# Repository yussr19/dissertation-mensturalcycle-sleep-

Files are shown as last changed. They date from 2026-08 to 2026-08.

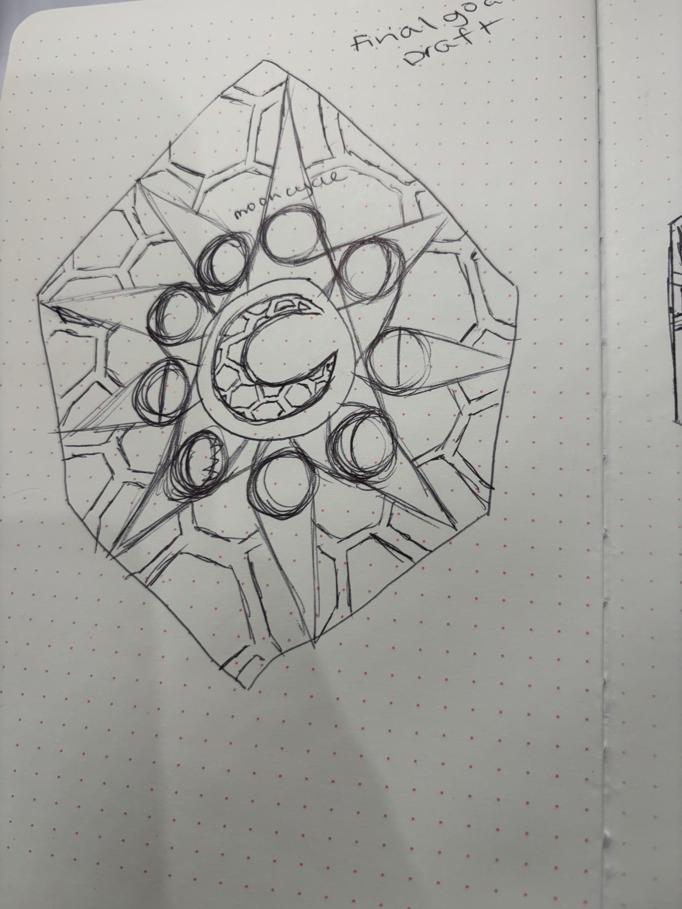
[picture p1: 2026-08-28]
sketches/IMG_7631 (2).jpeg

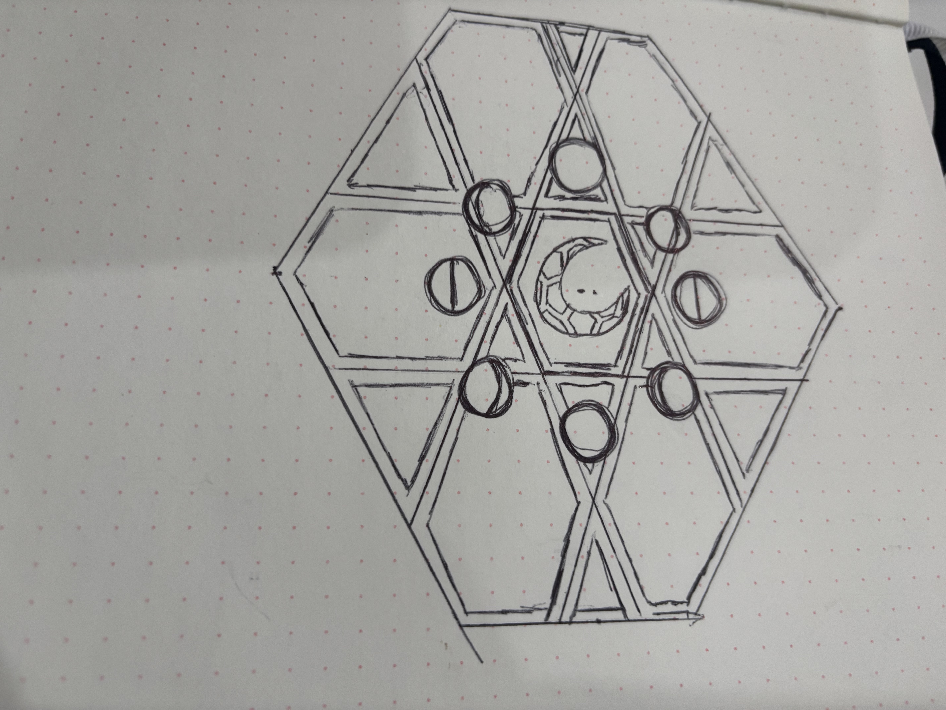
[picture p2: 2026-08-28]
sketches/IMG_7632 (1).jpeg

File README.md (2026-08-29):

# Luna — menstrual cycle and sleep sensing

A bedside sensing system that records sleep across a menstrual cycle and
renders the result as a physical drawing.

An LDC2410C mmWave radar and a Bangle.js 2 smartwatch log sleep to a
Raspberry Pi beside the bed. Nightly aggregation produces a sleep quality
score from 1 to 10, which is published over MQTT. An Arduino Nano 33 IoT
subscribes to that topic and drives a pen arm and a rotating disc, tracing
28 days of sleep as a spiral.

The recorder borrows its pen from a barograph — an instrument that has
drawn atmospheric pressure onto rotating paper since the nineteenth
century. Luna applies the same mechanism to a different cycle.

---

## Contents

- [How it works](#how-it-works)
- [Bill of materials](#bill-of-materials)
- [Repository layout](#repository-layout)
- [Part 1 — Bedside device](#part-1--bedside-device)
- [Part 2 — Luna recorder](#part-2--luna-recorder)
- [Part 3 — Exhibition mode](#part-3--exhibition-mode)
- [Enclosures](#enclosures)
- [Datasets](#datasets)
- [Analysis](#analysis)
- [Troubleshooting](#troubleshooting)
- [Known limitations](#known-limitations)

---

## How it works

```
Bangle.js 2                      LDC2410C radar
HR, IBI, survey                  presence, movement
     |                                 |
     | BLE                             | UART
     v                                 v
        Bedside Pi  —  sleeppi
        finalsleep.db · log_sleep.py · log_radar.py
        compute_sleep_metrics.py · compute_composite.py
        publish_sleep.py
                      |
                      | publish
                      v
        MQTT broker — mqtt.cetools.org:1884
        student/CASA0022/yussr/sleepquality
                      |
                      | subscribe
                      v
        Luna recorder — Arduino Nano 33 IoT
                   |            |
            SG90 pen arm    28BYJ-48 disc
          traces quality    1 turn / 28 days
```

The radar gives binary presence and movement. The Bangle gives heart rate
and inter-beat intervals. Together these produce sleep duration, efficiency,
wake after sleep onset (WASO) and movement percentage, which are combined
into a single 1–10 composite score per night.

---

## Bill of materials

### Bedside device

| Item | Qty | Notes | Approx. cost |
|---|-----|---|---|
| Raspberry Pi 3 Model A+ | 1 | Runs logging and nightly aggregation | £23 |
| microSD card, 32GB+ | 1 | Raspberry Pi OS | £8 |
| Official Pi power supply | 1 | Underpowered supplies cause boot failures | £10 |
| LDC2410C mmWave radar | 1 | UART presence/movement sensor | £6–10 |
| Bangle.js 2 smartwatch | 1 | Heart rate, IBI, morning survey | £99.60 |
| Jumper wires, female-female | 4 | Radar to Pi GPIO | £6 per pack |
| 3D printed sleep enclosure | 1 | `fusion/sleep enclousre final.stl` | filament only |

Subtotal: roughly **£153–157**, dominated by the smartwatch.

The Pi 3 Model A+ has 512MB of RAM and no Ethernet port. It is adequate for
logging and nightly aggregation, but it will not comfortably run a desktop
environment or a remote code editor alongside the sensing scripts. Work on
it over plain SSH rather than VS Code Remote, and keep anything non-essential
off it while it is recording.

### Luna recorder

| Item | Qty | Notes | Approx. cost |
|---|-----|---|---|
| Arduino Nano 33 IoT | 1 | WiFi + MQTT subscriber | £20–25 |
| SG90 micro servo | 1 | Pen arm, radial position | £3 |
| 28BYJ-48 stepper + ULN2003 driver | 1 | Usually sold as a pair | £5 |
| WS2812B LED strip, 28 LEDs | 1 | Exhibition lighting | £10 |
| Metcheck black fibre tip recording pen | 1 | Barograph nib, SKU MET-FIBRENIB | £16.50 |
| Paper discs | — | Cut to fit the turntable | £3 |
| 5V 2A power supply | 1 | Servo and stepper draw more than USB supplies | £10 |
| 3D printed recorder body | 1 | `fusion/luna recorder final.stl` | filament only |
| 3D printed pen dial and holder | 1 | `fusion/pen dial and holder.stl` | filament only |

Subtotal: roughly **£68–73**, excluding filament.

### Total

**Roughly £221–230** for the complete system.

Prices are UK retail including VAT, correct as of August 2026. The Bangle.js
2 figure comes from Espruino's shop and The Pi Hut; the recording pen from
Metcheck. 

### The pen

The pen is a barograph nib rather than an ordinary fineliner. It is 20.3mm
long and 4mm wide, with two dovetail grooves on the back that slot onto a
recording arm, and the nib lasts around twelve months of continuous use.
The pen holder in `fusion/pen dial and holder.stl` is dimensioned for these
grooves — an ordinary pen will not seat correctly without modifying the
model.

### Wiring — Luna recorder

| Component | Pin |
|---|-----|
| SG90 servo signal | D6 |
| 28BYJ-48 via ULN2003 IN1 | D8 |
| 28BYJ-48 via ULN2003 IN2 | D10 |
| 28BYJ-48 via ULN2003 IN3 | D9 |
| 28BYJ-48 via ULN2003 IN4 | D11 |

Note the IN2/IN3 ordering — it is not sequential. This matches the
`Stepper disc(STEPS_PER_REV, 8, 10, 9, 11)` declaration in the sketch.

### Wiring — LDC2410C to Raspberry Pi

| LDC2410C | Pi header pin |
|---|---|
| VCC | 2 or 4 (5V) |
| GND | 6 |
| TX | 10 (GPIO15, Pi RX) |
| RX | 8 (GPIO14, Pi TX) |

Diagrams and placement notes are in `sketches/`.

---

## Repository layout

| Path | Contents |
|---|---|
| `final_code/bedside_device/` | Logging, metrics and publishing on the bedside Pi |
| `final_code/exhibition/` | Exhibition publisher and the Arduino sketch |
| `test_code/` | Hardware sanity-check scripts |
| `analysis/` | Statistics and figure generation |
| `datasets/` | Exported sleep, radar and survey data |
| `fusion/` | Fusion 360 sources and STL exports |
| `sketches/` | Diagrams and design notes |

---

## Part 1 — Bedside device

### Prepare the Pi

Flash Raspberry Pi OS, then free the serial port for the radar:

```bash
sudo raspi-config
# Interface Options -> Serial Port
#   login shell over serial?      -> No
#   serial port hardware enabled? -> Yes
sudo reboot
```

### Install dependencies

```bash
sudo apt update
sudo apt install -y python3-pip sqlite3
pip3 install pyserial paho-mqtt bleak
```

### Clone and test

```bash
git clone https://github.com/yussr19/dissertation-mensturalcycle-sleep-.git
cd dissertation-mensturalcycle-sleep-
python3 test_code/test_radar.py
```

Walk in front of the sensor. You should see `presence=True movement=True`,
then `movement=False` when you sit still. If nothing prints, see
[Troubleshooting](#troubleshooting).

### The pipeline

| Script | Purpose |
|---|---|
| `log_radar.py` | Logs presence and movement to `finalsleep.db` |
| `log_sleep.py` | Logs Bangle.js data to `finalsleep.db` |
| `sync_bangle.py` | Pulls JSON off the watch over BLE into SQLite |
| `compute_sleep_metrics.py` | Duration, efficiency, WASO, movement % |
| `compute_composite.py` | Combines metrics into a 1–10 score |
| `publish_sleep.py` | Publishes the score to MQTT |

`log_radar.py` runs continuously overnight. The compute and publish steps
run once per day after waking.

To schedule them, add entries to the Pi's crontab with `crontab -e`. For
example, to run the daily chain at 10am:

```
0 10 * * * cd /home/USER/dissertation-mensturalcycle-sleep-/final_code/bedside_device && /usr/bin/python3 compute_sleep_metrics.py
5 10 * * * cd /home/USER/dissertation-mensturalcycle-sleep-/final_code/bedside_device && /usr/bin/python3 compute_composite.py
10 10 * * * cd /home/USER/dissertation-mensturalcycle-sleep-/final_code/bedside_device && /usr/bin/python3 publish_sleep.py
```

Use absolute paths — cron does not inherit your shell environment, and
relative paths are the most common reason a scheduled script works by hand
but silently fails overnight.

---

## Part 2 — Luna recorder

### Arduino setup

Install the Arduino IDE, add the **Arduino SAMD Boards** package, select
**Arduino Nano 33 IoT**, and install these libraries via Library Manager:

- WiFiNINA
- PubSubClient
- Servo
- Stepper
- ArduinoJson

### Credentials

The sketch reads credentials from `config.h`, which is not in this
repository. Create it from the template:

```bash
cd final_code/exhibition/final_exhib
cp config.example.h config.h
```

Fill in your MQTT username and password and up to two WiFi networks. The
sketch tries them in order, which is useful when moving between a home
network and a venue.

### Calibration

Two constants in the sketch set where the pen sits:

```cpp
const int ANGLE_Q1  = 20;   // sleep quality 1  — inner ring
const int ANGLE_Q10 = 160;  // sleep quality 10 — outer ring
```

Adjust these after assembly so the pen reaches the inner and outer edges of
the paper without binding.

### Flash and check

Upload the sketch, open Serial Monitor at 9600 baud. You should see the WiFi
and MQTT connections succeed, then `Waiting for sleep-quality data...`.

---

## Part 3 — Exhibition mode

For an exhibition the bedside Pi is not present, so a second Pi replays a
recorded 28-day cycle from the database.

```bash
export MQTT_USER="your_username"
export MQTT_PASS="your_password"

cd final_code/exhibition
python3 publish_exhibition.py --inspect        # check the data first
python3 publish_exhibition.py --seed           # fill the recorder history
python3 publish_exhibition.py --interval 10    # fast test
python3 publish_exhibition.py                  # live: one day per 10 min
```

The publisher sends one small JSON message per day:

```json
{"quality": 7, "cycle_day": 12}
```

Messages are retained, so a recorder that is power-cycled mid-exhibition
picks up the current value immediately rather than standing still.

Put the credentials in `~/.bashrc` so they survive reboots:

```bash
echo 'export MQTT_USER="your_username"' >> ~/.bashrc
echo 'export MQTT_PASS="your_password"' >> ~/.bashrc
source ~/.bashrc
```

---

## Enclosures

`fusion/` holds both Fusion 360 sources and STL exports.

| File | Part |
|---|---|
| `luna recorder final.stl` | Recorder body |
| `pen dial and holder.stl` | Pen arm and dial |
| `sleep enclousre final.stl` | Bedside sensor housing |

The `.f3d` and `.f3z` files are the editable Fusion 360 sources. The STLs
are ready to slice.

---

## Datasets

| File | Contents |
|---|---|
| `datasets/sleep_log.csv` | Nightly sleep records and composite scores |
| `datasets/radar_sample.csv` | Radar output samples |
| `datasets/survey_responses.csv` | 17 exhibition visitor responses |

Survey responses record date, gender, age band and one comprehension
question. They carry no names, emails or precise timestamps.

---

## Analysis

```bash
cd analysis
python3 results_statistics.py
python3 make_figure_5_1.py
```

`make_figure_5_1.py` produces the 28-day circular visualisation.

Both scripts read from the sleep database. If you are reproducing this
without the original database, point them at `datasets/sleep_log.csv`
instead by editing the path at the top of each script.

---

## Troubleshooting

**Radar prints nothing.** Almost always baud rate or the serial console.
The LDC2410C defaults to 256000, though some boards ship at 115200. Confirm
the serial console is disabled in `raspi-config`.

**Presence flickers.** A single frame reading "no target" mid-sleep is
normal. Aggregation applies a hold timer so a brief dropout is not read as
someone leaving the bed.

**Sitting still reads as absent.** Stationary detection depends on the
per-gate sensitivity thresholds and on what is behind the person. This is
tuning, not a fault.

**Recorder connects but never moves.** Check the payload keys are exactly
`quality` and `cycle_day`. The sketch uses `StaticJsonDocument<128>`, so an
oversized message fails to deserialize and is silently ignored.

**Recorder drops off MQTT during replay.** `replayHistory()` blocks while
it sweeps, during which `mqtt.loop()` does not run. Long sweeps can exceed
the keepalive. It reconnects, but messages arriving mid-sweep are lost.

**Scheduled scripts work by hand but not overnight.** Cron runs with a
minimal environment. Use absolute paths and check `/var/log/syslog`.

---

## Known limitations

- The LDC2410C reports presence along a single beam. It does not count people
  or track position, so the system assumes one occupant.
- Sleep staging is inferred from movement and heart rate, not EEG. Values are
  relative indicators rather than clinical measurements.
- The disc advances during replay as well as on its own schedule; over a long
  exhibition these two can drift out of step.
- MQTT credentials are transmitted without TLS on port 1884.
- The recorder holds 28 days in memory with no persistence. A power cycle
  loses the history until the publisher re-seeds it.

---

## License

MIT.

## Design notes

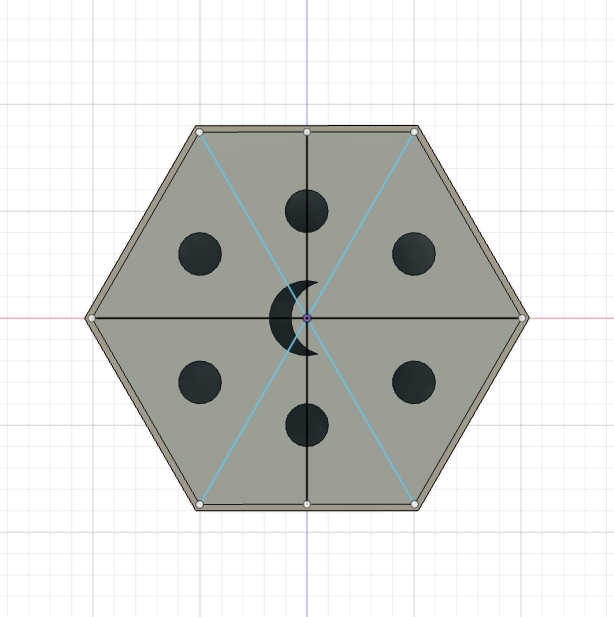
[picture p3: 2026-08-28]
sketches/Screenshot%202026-06-07%20at%2019.21.58.png

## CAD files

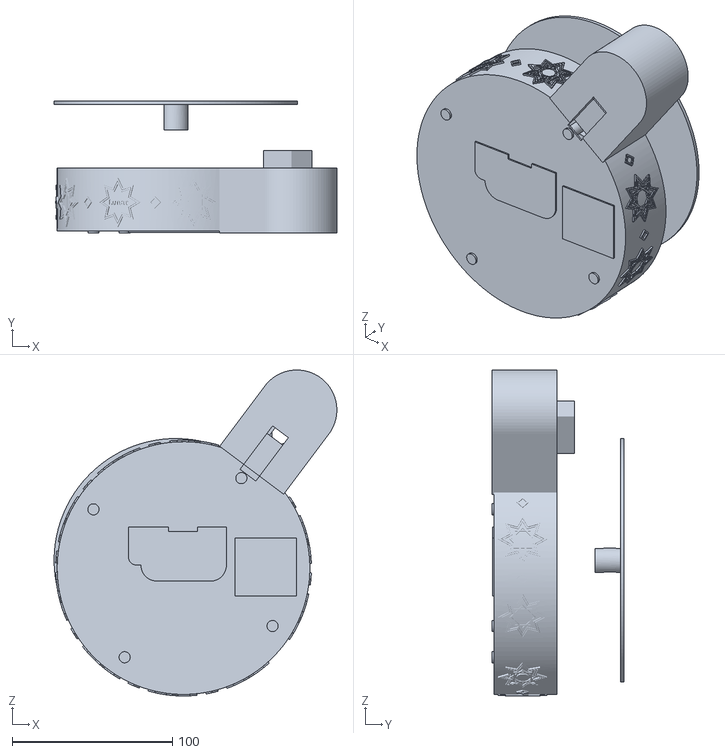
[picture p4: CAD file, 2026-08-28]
fusion/luna recorder final.stl
176.5 x 82.3 x 203.5

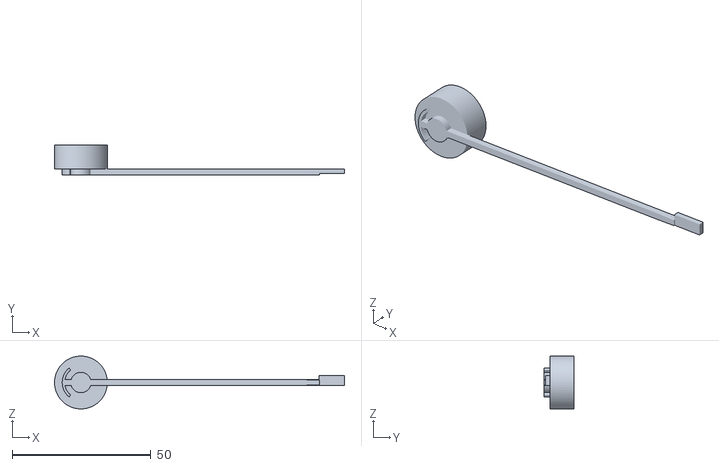
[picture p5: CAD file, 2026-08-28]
fusion/pen dial and holder.stl
104.5 x 10.7 x 19.0

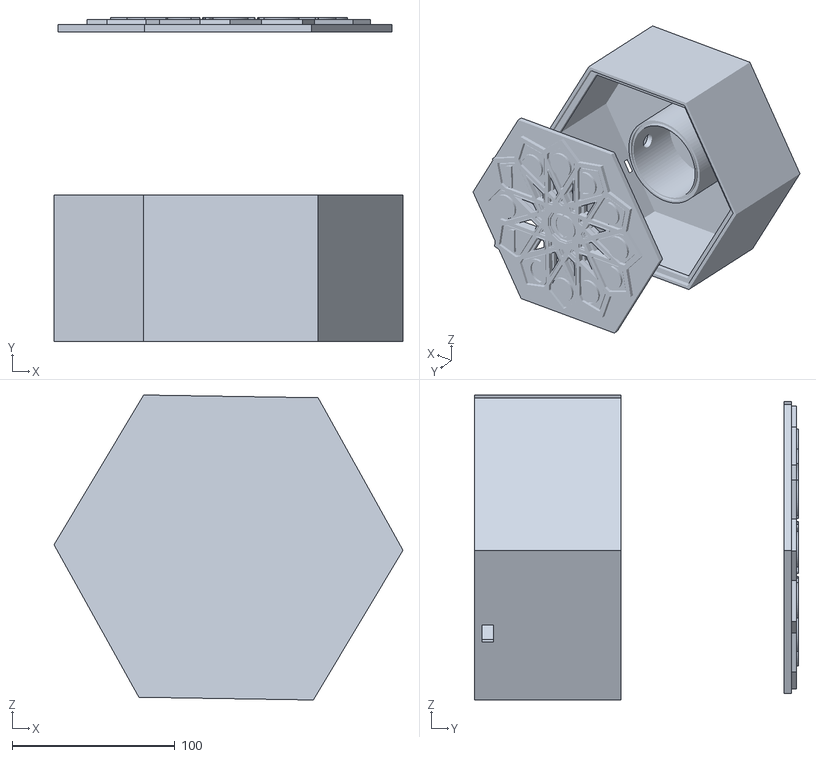
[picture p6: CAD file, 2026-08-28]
fusion/sleep enclousre final.stl
214.7 x 199.4 x 187.7

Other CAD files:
fusion/fusion/luna recorder final.f3z
fusion/pen dial and holder final.f3d
fusion/sleep enclousre final.f3d

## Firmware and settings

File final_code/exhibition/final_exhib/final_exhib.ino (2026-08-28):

#include "config.h"

#include <WiFiNINA.h>
#include <PubSubClient.h>
#include <Servo.h>
#include <Stepper.h>
#include <ArduinoJson.h>

// ============================================================
// WIFI / MQTT
// ============================================================
// Credentials live in config.h, which is gitignored.
// Copy config.example.h to config.h and fill in your values.

const char* MQTT_BROKER = "mqtt.cetools.org";
const int   MQTT_PORT = 1884;

const char* TOPIC = "student/CASA0022/yussr/sleepquality";


// ============================================================
// HARDWARE
// ============================================================

const int SERVO_PIN = 6;
const int STEPS_PER_REV = 2048;

Stepper disc(STEPS_PER_REV, 8, 10, 9, 11);
Servo penArm;


// ============================================================
// SERVO CALIBRATION
// ============================================================

const int ANGLE_Q1  = 20;   // sleep quality 1  = inner ring
const int ANGLE_Q10 = 160;  // sleep quality 10 = outer ring


// ============================================================
// TIMING
// ============================================================

const unsigned long REPLAY_INTERVAL_MS = 600000UL;  // 10 minutes
unsigned long lastReplay = 0;


// ============================================================
// DATA
// ============================================================
// No synthetic data. These values are filled from MQTT.

int  history[28] = {0};
bool receivedDay[28] = {false};
int  receivedCount = 0;
int  latestQuality = 0;
int  latestCycleDay = 0;


// ============================================================
// NETWORK OBJECTS
// ============================================================

WiFiClient wifi;
PubSubClient mqtt(wifi);


// ============================================================
// SERVO
// ============================================================

int currentAngle = -1;

int qualityToAngle(int q) {
  q = constrain(q, 1, 10);
  return map(q, 1, 10, ANGLE_Q1, ANGLE_Q10);
}

void moveServoSlowly(int targetAngle, int stepDelayMs) {

  if (currentAngle == -1) {
    penArm.write(targetAngle);
    currentAngle = targetAngle;
    return;
  }

  int step = (targetAngle > currentAngle) ? 1 : -1;

  while (currentAngle != targetAngle) {
    currentAngle += step;
    penArm.write(currentAngle);
    delay(stepDelayMs);
  }
}


// ============================================================
// PRINT CURRENT HISTORY
// ============================================================

void printHistory() {

  Serial.println();
  Serial.println("Current 28-day history:");

  for (int i = 0; i < 28; i++) {
    Serial.print("Day ");
    Serial.print(i + 1);
    Serial.print(": ");
    if (receivedDay[i]) {
      Serial.println(history[i]);
    } else {
      Serial.println("-");
    }
  }

  Serial.print("Days received: ");
  Serial.print(receivedCount);
  Serial.println("/28");
  Serial.println();
}


// ============================================================
// MQTT CALLBACK
// ============================================================

void mqttCallback(char* topic, byte* payload, unsigned int len) {

  StaticJsonDocument<128> doc;

  DeserializationError error = deserializeJson(doc, payload, len);

  if (error) {
    Serial.print("JSON error: ");
    Serial.println(error.c_str());
    return;
  }

  if (!doc.containsKey("quality") || !doc.containsKey("cycle_day")) {
    Serial.println("MQTT message missing quality or cycle_day");
    return;
  }

  int q   = doc["quality"];
  int day = doc["cycle_day"];

  if (q < 1 || q > 10) {
    Serial.print("Invalid quality: ");
    Serial.println(q);
    return;
  }

  if (day < 1 || day > 28) {
    Serial.print("Invalid cycle day: ");
    Serial.println(day);
    return;
  }

  int index = day - 1;
  history[index] = q;

  if (!receivedDay[index]) {
    receivedDay[index] = true;
    receivedCount++;
  }

  latestQuality  = q;
  latestCycleDay = day;

  Serial.print("Received cycle day ");
  Serial.print(day);
  Serial.print(" | sleep quality ");
  Serial.println(q);

  moveServoSlowly(qualityToAngle(q), 20);

  if (receivedCount == 28) {
    Serial.println();
    Serial.println("FULL 28-DAY DATASET RECEIVED");
    printHistory();
  }
}


// ============================================================
// WIFI CONNECTION
// ============================================================

void connectWiFi() {

  const char* ssids[]  = { WIFI_SSID_1, WIFI_SSID_2 };
  const char* passes[] = { WIFI_PASS_1, WIFI_PASS_2 };

  for (int i = 0; i < 2 && WiFi.status() != WL_CONNECTED; i++) {

    Serial.print("WiFi try: ");
    Serial.println(ssids[i]);

    WiFi.begin(ssids[i], passes[i]);

    unsigned long start = millis();

    while (WiFi.status() != WL_CONNECTED && millis() - start < 15000) {
      delay(500);
    }
  }

  if (WiFi.status() == WL_CONNECTED) {
    Serial.println("WiFi connected");
    Serial.print("IP: ");
    Serial.println(WiFi.localIP());
  } else {
    Serial.println("WiFi connection failed");
  }
}


// ============================================================
// MQTT CONNECTION
// ============================================================

void connectMQTT() {

  if (WiFi.status() != WL_CONNECTED) return;

  while (!mqtt.connected()) {

    Serial.println("Connecting to MQTT...");

    if (mqtt.connect("luna-recorder", MQTT_USER, MQTT_PASSWD)) {

      Serial.println("MQTT connected");
      mqtt.subscribe(TOPIC);
      Serial.print("Subscribed to: ");
      Serial.println(TOPIC);

    } else {

      Serial.print("MQTT failed, state=");
      Serial.println(mqtt.state());
      delay(3000);
    }
  }
}


// ============================================================
// REPLAY THE RECEIVED 28-DAY DATA
// ============================================================

void replayHistory() {

  if (receivedCount == 0) {
    Serial.println("No data received yet.");
    return;
  }

  Serial.println();
  Serial.println("Starting received-data replay...");

  for (int day = 0; day < 28; day++) {

    if (!receivedDay[day]) continue;

    int q = history[day];

    Serial.print("Replay day ");
    Serial.print(day + 1);
    Serial.print(" quality ");
    Serial.println(q);

    // Move pen radially
    moveServoSlowly(qualityToAngle(q), 15);

    // Advance disc one cycle day: 2048 / 28 = ~73 steps
    int stepsPerDay = STEPS_PER_REV / 28;
    disc.step(stepsPerDay);

    delay(400);
  }

  Serial.println("Replay complete.");

  if (latestQuality >= 1) {
    moveServoSlowly(qualityToAngle(latestQuality), 15);
  }
}


// ============================================================
// SETUP
// ============================================================

void setup() {

  Serial.begin(9600);
  delay(1500);

  Serial.println();
  Serial.println("Luna recorder starting");

  penArm.attach(SERVO_PIN);
  disc.setSpeed(5);

  mqtt.setServer(MQTT_BROKER, MQTT_PORT);
  mqtt.setCallback(mqttCallback);

  connectWiFi();
  connectMQTT();

  lastReplay = millis();

  Serial.println("Waiting for sleep-quality data...");
}


// ============================================================
// LOOP
// ============================================================

void loop() {

  if (WiFi.status() != WL_CONNECTED) {
    connectWiFi();
  }

  if (WiFi.status() == WL_CONNECTED && !mqtt.connected()) {
    connectMQTT();
  }

  mqtt.loop();

  unsigned long now = millis();

  if (now - lastReplay >= REPLAY_INTERVAL_MS) {
    replayHistory();
    // replayHistory() blocks, so reset the timer after it returns
    lastReplay = millis();
  }
}

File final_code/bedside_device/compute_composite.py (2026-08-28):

#!/usr/bin/env python3

"""
compute_composite.py

Derives an equal-weight DEVICE-ONLY composite sleep index from
nightly measures stored in sleep_log.

The composite uses:
    - heart_rate
    - hrv
    - movement_pct
    - sleep_duration_min
    - sleep_efficiency

Subjective measures are deliberately excluded:
    - sleep_quality
    - energy

Each contributing measure is:
  1. z-scored across the full record
  2. reversed if high values mean worse sleep
  3. equally averaged
  4. rescaled to 1-10

This keeps the composite independent from the subjective app
and diary data so that device-derived and subjective measures
can be compared in the Results.

Usage:
    python3 compute_composite.py --dry-run
    python3 compute_composite.py
"""

import sqlite3
import sys
import statistics


DB_PATH = "/home/yussr19/analysis/finalsleep_.db"


# --------------------------------------------------
# DEVICE-ONLY CONTRIBUTORS
# --------------------------------------------------

CONTRIBUTORS = [

    (
        "heart_rate",
        False
    ),

    (
        "hrv",
        True
    ),

    (
        "movement_pct",
        False
    ),

    (
        "sleep_duration_min",
        True
    ),

    (
        "sleep_efficiency",
        True
    ),

]


# Subjective sleep quality is NOT included.
INCLUDE_SELF_REPORT = False

# A night may be missing at most one usable
# contributor before being excluded.
MAX_MISSING = 1


def existing_columns(conn):
    """Return sleep_log column names."""

    return {
        r[1]
        for r in conn.execute(
            "PRAGMA table_info(sleep_log)"
        ).fetchall()
    }


def fetch_rows(conn, contributors):
    """Load nightly rows."""

    cols = [
        "id",
        "date",
        "cycle_day",
        "sleep_quality",
        "energy",
    ] + [
        c
        for c, _
        in contributors
    ]

    # Remove duplicates while preserving order.
    cols = list(
        dict.fromkeys(cols)
    )

    q = (
        f"SELECT "
        f"{', '.join(cols)} "
        f"FROM sleep_log "
        f"ORDER BY id ASC"
    )

    return [
        dict(
            zip(cols, r)
        )
        for r
        in conn.execute(q).fetchall()
    ]


def zscores(values):
    """
    Return a function mapping a raw value
    to its z-score.

    Returns None if there are fewer than
    two usable values or no variation.
    """

    clean = [
        v
        for v in values
        if v is not None
    ]

    if len(clean) < 2:
        return None

    mean = statistics.mean(clean)
    sd = statistics.pstdev(clean)

    if sd == 0:
        return None

    return lambda v: (
        v - mean
    ) / sd


def main():

    dry = (
        "--dry-run"
        in sys.argv
    )

    conn = sqlite3.connect(
        DB_PATH
    )

    # --------------------------------------------------
    # Check sleep_log exists
    # --------------------------------------------------

    tables = {
        r[0]
        for r in conn.execute(
            """
            SELECT name
            FROM sqlite_master
            WHERE type='table'
            """
        ).fetchall()
    }

    if "sleep_log" not in tables:

        print(
            "ERROR: sleep_log table not found."
        )

        conn.close()
        return

    present = existing_columns(
        conn
    )

    # --------------------------------------------------
    # Adaptive contributors
    # --------------------------------------------------

    contributors = []

    for col, higher_better in CONTRIBUTORS:

        if col in present:

            contributors.append(
                (
                    col,
                    higher_better
                )
            )

        else:

            print(
                f"(column '{col}' "
                "not in sleep_log - skipped)"
            )

    if (
        INCLUDE_SELF_REPORT
        and
        "sleep_quality" in present
    ):

        contributors.append(
            (
                "sleep_quality",
                True
            )
        )

    if not contributors:

        print(
            "No contributing columns found."
        )

        conn.close()
        return

    # --------------------------------------------------
    # Ensure composite column exists
    # --------------------------------------------------

    if (
        "composite_quality"
        not in present
    ):

        conn.execute(
            """
            ALTER TABLE sleep_log
            ADD COLUMN composite_quality REAL
            """
        )

        conn.commit()

        print(
            "Added column: composite_quality"
        )

    # --------------------------------------------------
    # Load nights
    # --------------------------------------------------

    rows = fetch_rows(
        conn,
        contributors
    )

    if not rows:

        print(
            "No rows in sleep_log."
        )

        conn.close()
        return

    # --------------------------------------------------
    # Build z-score scalers
    # --------------------------------------------------

    scalers = {}

    for col, _ in contributors:

        f = zscores(
            [
                r.get(col)
                for r in rows
            ]
        )

        if f is None:

            print(
                f"(skipping '{col}': "
                "fewer than two values "
                "or no variation)"
            )

        else:

            scalers[col] = f

    if not scalers:

        print(
            "No usable measures."
        )

        conn.close()
        return

    # --------------------------------------------------
    # Mean z-score per night
    # --------------------------------------------------

    raw = {}

    for r in rows:

        zs = []
        missing = 0

        for (
            col,
            higher_better
        ) in contributors:

            if col not in scalers:
                continue

            v = r.get(col)

            if v is None:
                missing += 1
                continue

            z = scalers[col](v)

            if higher_better:
                zs.append(z)
            else:
                zs.append(-z)

        if (
            not zs
            or
            missing > MAX_MISSING
        ):
            continue

        raw[r["id"]] = (
            sum(zs)
            / len(zs)
        )

    if not raw:

        print(
            "\nNo nights met "
            "the completeness rule."
        )

        conn.close()
        return

    # --------------------------------------------------
    # Rescale mean z-score to 1-10
    # --------------------------------------------------

    lo = min(
        raw.values()
    )

    hi = max(
        raw.values()
    )

    span = (
        hi - lo
    ) or 1.0

    scaled = {

        i:
        1
        + 9
        * (
            (v - lo)
            / span
        )
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

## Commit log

2026-06-16 Initial commit: sensor scripts and fan control
2026-08-28 Rename led_bedtime.py to test led_bedtime.py
2026-08-28 Reorganise test code, replace radar test with LD2410C presence script, remove fan code
    [test_led_bedtime.py, test_leds.py, test_radar.py]
2026-08-28 Pi work: log updates, LD2410 test, exhibition and LED scripts
2026-08-28 Add bedside device pipeline and analysis scripts
2026-08-28 Add sleep log and radar sample datasets
    [radar_sample.csv, sleep_log.csv]
2026-08-28 Add exhibition survey responses
    [survey_responses.csv]
2026-08-28 Add Fusion and STL files
    [luna recorder final.f3z, luna recorder final.stl, pen dial and holder final.f3d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]
2026-08-28 Flatten fusion folder, remove .DS_Store
    [luna recorder final.stl, pen dial and holder final.f3d, pen dial and holder.stl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]
